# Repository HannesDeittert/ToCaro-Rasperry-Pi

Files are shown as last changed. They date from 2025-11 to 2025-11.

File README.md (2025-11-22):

# ToCaro-Raspberry-Pi

#### Funktionsweise

Das Seil wird über einen Getriebemotor auf eine Seilwinde aufgezogen (siehe CAD-Modell). Die Regelung des Motors erfolgt dabei positionsgesteuert über Hall-Encoder die am Motor verbaut sind. Beim Drehen des Motors werden Rechtecksignale an den digitalen Input des Arduinos gesendet. Die Software kann dann die ausgelösten Flanken erkennen und so durch Zählen der Schritte die Position bestimmen. Die Ansteuerung des Motors erfolgt aktuell über das adafruit motor shield v2.3 welches mittels I2C mit dem Arduino verbunden ist. Auf dem shield sitzen drei chips, ein PCA9685 der das I2C Signal des Arduinos in PWM Signale Wandelt und zwei TB6612 MOSFETs die daraus die Spannung an die Motoren freigaben. Den aktuellen Code hab ich dir auf der nextcloud abgelegt. 

#### Ziel

Grundsätzlich soll erstmal alles so funktionieren wie es jetzt funktioniert, nur statt mit dem Arduino mit einem Raspberry Pi 5 betrieben werden. 
In einem ersten Schritt wäre es klasse, wenn du die Motorsteuerung über das Adafruit Motor Shield statt mit dem Arduino mit dem Pi laufen lässt. Dabei reicht es auch wenn erstmal ein Motor läuft.
Alex hat ein PCB designed auf dem (neben anderen Sachen) Power Delivery und die chips des motor shields drauf sind. Am Ende soll alles darüber laufen. Bis das da ist, denke ich du kannst ganz gut vorarbeiten wenn du nur den Arduino durch den PI ersetzt. Auf dem finalen Board sollte dann ja eigentlich alles genauso laufen :D  

#### Links zu den Bauteilen

Motor https://www.dfrobot.com/product-1436.html
Adafruit Motor Shield V2.3 https://www.adafruit.com/product/1438
PWM Chip auf dem Motor Shield PCA9685 https://www.digikey.de/de/htmldatasheets/production/1640697/0/0/1/pca9685-datasheet
TB6612 MOSFET auf dem Motor Shield https://www.digikey.de/en/products/detail/toshiba-semiconductor-and-storage/TB6612FNG-C-8-EL/1730070

#### Raspberry Pi Code (neu)

Der Pi-Code liegt unter `raspberry_pi/` als Python-Paket `tocado_pi`:
- `src/tocado_pi/hardware.py` – Adapter für Motor Shield (PCA9685/TB6612) und Encoder.
- `src/tocado_pi/motor_control.py` – einfache Positionsregelung mit Grenzen/Sicherheits-Timeout.
- `src/tocado_pi/cli.py` – kleines CLI zum Drehen/Positionieren (`python -m tocado_pi.cli spin --duty 0.5 --seconds 2`).
- `scripts/smoke_test.py` – minimalistischer Spin-Test.
- `tests/` – pytest-Tests mit fakes (kein echtes Hardware-Setup nötig).

Setup auf dem Pi:
```
cd raspberry_pi
python -m venv .venv
source .venv/bin/activate
pip install -r requirements.txt -r dev-requirements.txt
pytest
PYTHONPATH=src python -m tocado_pi.cli --help
```

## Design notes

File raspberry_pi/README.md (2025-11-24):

# Raspberry Pi code guide

Raspberry Pi control code for the Adafruit Motor Shield V2.3 (PCA9685 + TB6612) with Hall encoders.

## Layout
- `src/tocado_pi/config.py` – config dataclasses (pins, I2C, motion limits).
- `src/tocado_pi/hardware.py` – hardware adapters (MotorKit driver + encoder GPIO reader).
- `src/tocado_pi/motor_control.py` – simple move/spin controls with limits and stop.
- `src/tocado_pi/cli.py` – CLI entrypoint (`spin`, `move`).
- `scripts/smoke_test.py` – minimal spin test helper.
- `scripts/debug_motor_shield.py` – interactive checker for supply, all 4 channels, and encoder ticks.
- `scripts/motor_web_ui.py` – small web UI to view encoder counts and jog one or several motor channels.
- `tests/` – pytest unit tests with fakes (no hardware needed).
- `requirements.txt` / `dev-requirements.txt` – runtime vs. dev deps.

## Quickstart (on the Pi)
```
cd raspberry_pi
python3 -m venv .venv
source .venv/bin/activate
pip install -r requirements.txt -r dev-requirements.txt
```

Check I2C for the Motor Shield (expect address 0x60):
```
i2cdetect -y 1
```

Run tests (offline):
```
pytest
```

CLI examples (set your encoder GPIO BCM pins):
```
PYTHONPATH=src python -m tocado_pi.cli spin --duty 0.3 --seconds 2 --pin-a <BCM_A> --pin-b <BCM_B> --motor-channel 1
PYTHONPATH=src python -m tocado_pi.cli move --target 500 --duty 0.5 --pin-a <BCM_A> --pin-b <BCM_B>
```

Smoke test script (short spin):
```
PYTHONPATH=src python scripts/smoke_test.py --duty 0.4 --seconds 2 --pin-a <BCM_A> --pin-b <BCM_B>
```

Debug the shield (pulses M1–M4, prompts for terminal observations, reports encoder counts):
```
PYTHONPATH=src python scripts/debug_motor_shield.py --duty 1.0 --seconds 1 --pin-a <BCM_A> --pin-b <BCM_B>
```

Web UI (encoder readout + forward/reverse/brake controls):
```
PYTHONPATH=src python scripts/motor_web_ui.py --motor-channel 1 --pin-a <BCM_A> --pin-b <BCM_B>
# Multi-motor example with three encoders:
# PYTHONPATH=src python scripts/motor_web_ui.py --motor 1:17:27 --motor 2:22:23 --motor 3:24:25
# Then open http://<pi-ip>:8000 in your browser.
```

## Wiring notes
- Motor Shield uses only I2C to the Pi; motors on M1–M4 terminals with separate motor supply.
- Encoders: treat A/B as open-collector; power at 3.3 V, GND common, use Pi pull-ups (`INPUT_PULLUP` default in code). Pi GPIOs are not 5 V tolerant; if you must use 5 V on the encoder side, add level shifting or pull-ups to 3.3 V instead.

## Files and intent
- `hardware.py`: isolates MotorKit import and GPIO usage; supports injecting fakes for tests.
- `motor_control.py`: moves toward a target encoder count with bounds, timeout, stop flag; spins for a duration.
- `cli.py`: convenient manual control without writing code; logs at INFO by default.
- `tests/test_motor_control.py`: covers move/timeout/spin behavior using fake motor + encoder.

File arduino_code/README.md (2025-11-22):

# Arduino sketches overview

Reference notes for the existing Arduino implementations that drive the Adafruit Motor Shield V2.3 (PCA9685 + dual TB6612). This summarizes wiring, data flow, and behavior to inform the Raspberry Pi port.

## Wiring / pinout
- Motor Shield V2.3 on I2C (addr 0x60 by default) using Arduino SDA/SCL.
- Motors: M1, M2, M3 outputs on the shield (no M4 in current code).
- Hall encoders (quadrature) per motor:  
  - Motor 1: `ENC1_A = 2`, `ENC1_B = 3`  
  - Motor 2: `ENC2_A = 8`, `ENC2_B = 9`  
  - Motor 3: `ENC3_A = 6`, `ENC3_B = 7`
- Interrupts are attached on the A channels only (`CHANGE` on ENC*_A). ISR reads A and B to determine direction.
- Pull-ups: all encoder inputs use `INPUT_PULLUP`.

## Sketch summaries
### Three_Motors_Chat.ino (main logic)
- Initializes three DC motors and three quadrature encoders.
- Persisted position per motor in EEPROM as signed long; guarded by magic value `0xBEEF`.
- Encoder ISR per motor:
  - Runs on A channel edges, reads A/B to increment or decrement a volatile count.
  - Updates `lastChange*` timestamps used to decide when to write EEPROM.
- Setup:
  - Loads encoder counts from EEPROM (or zeros and writes defaults).
  - Computes target steps from desired travel distances:  
    `stepsPerMM = hall_feedback_resolution / (2π * (winch_diameter/2))`  
    Targets: distance1=25mm, distance2=35mm, distance3=35mm.
  - Motors: speeds set to 30/40/40; initial direction FORWARD.
- Loop behavior:
  - Copies volatile counts atomically.
  - Direction control per motor: if count >= steps target, run BACKWARD; if count < 0, run FORWARD. This creates a back-and-forth motion between 0 and the target count.
  - Every `T_IDLE = 5000ms`, if a motor’s count changed since last save, writes all three counts to EEPROM.
  - Prints counts vs targets for all motors, then delays `delaytime = 100ms`.

### Wire_Tensioning.ino
- Minimal setup to spin only motor 2 at speed 20 (M1 and M3 are stopped).
- No encoder usage; likely a quick tensioning/smoke test.

### EEPROM_Clear.ino
- Utility to clear the entire EEPROM to `0xFF` via `EEPROM.update` loop; prints progress over Serial.

## Behavioral notes / assumptions
- Control loop is open-loop on PWM speed with closed-loop only on position count bounds (no PID). The motor reverses at 0 and at the computed step limit.
- Encoder resolution constant: `hall_feedback_resolution = 1050/2` (counts per revolution / 2?). Winch diameter = 7.0 units (likely mm).
- Persistence occurs only after 5s of inactivity per motor to reduce EEPROM wear.
- Serial output at 115200 baud: simple telemetry of counts/targets.

## Raspberry Pi porting considerations
- Replace Adafruit_MotorShield C++ library with `adafruit-circuitpython-motorkit` (PCA9685 + TB6612) over I2C.
- Use GPIO edge detection for encoder A channels; read B to determine direction. Apply debouncing if needed.
- Provide configurable pin mapping, winch diameter, encoder resolution, speed/limit values.
- Add safety: max runtime/travel, faulted motor disable, optional soft-start on speed changes.
- Mirror EEPROM persistence via a JSON/state file (or skip) to preserve position across reboots if required.

These notes should keep Arduino intent visible while we build the Raspberry Pi implementation.

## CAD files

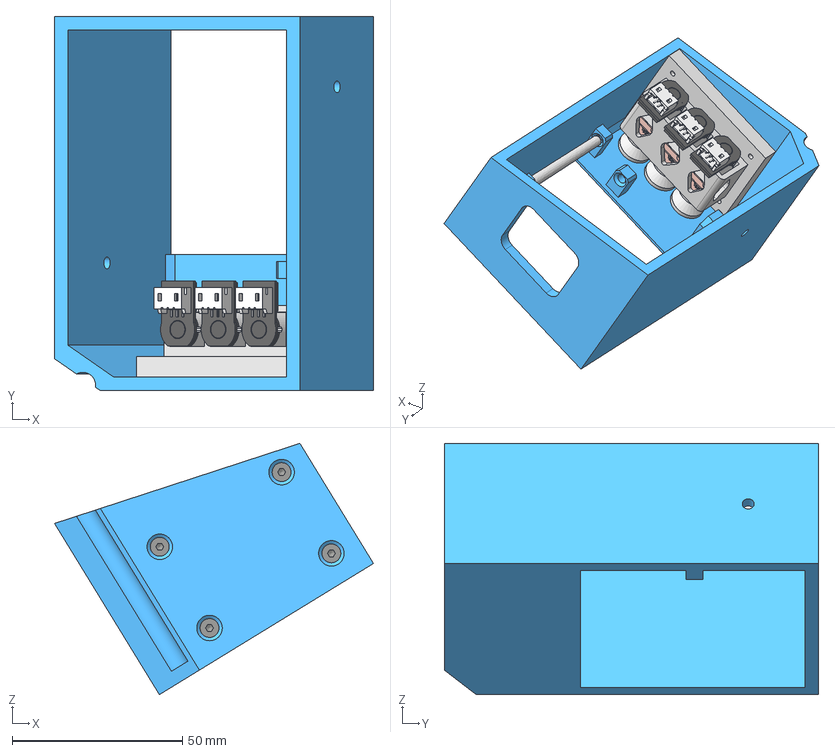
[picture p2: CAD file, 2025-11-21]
cad_doc/ElectronicsV2.stp
93.7 x 110.0 x 73.9 mm
Motorhalter Electronics Box V4
ruthex RX-M3-5,7 x 4
Gearmotor, Micro Metal, 50.1, with Driver_1 x 3
C-1775469-3 x 3
PCBA x 3
Seilwinde x 3
ISO 10642 - M3 x 8 x 7
Electronics Box V5
Tube1

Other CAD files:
cad_doc/ElectronicsV2.iam

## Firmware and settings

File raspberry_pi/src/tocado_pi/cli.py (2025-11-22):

"""
Small CLI for manual Raspberry Pi motor checks.

Examples:
- Spin for 2 seconds at 50% duty: `python -m tocado_pi.cli spin --duty 0.5 --seconds 2`
- Move to encoder count 500 at 60% duty: `python -m tocado_pi.cli move --target 500 --duty 0.6`
"""

from __future__ import annotations

import argparse
import logging
import sys

from .config import EncoderConfig, MotorConfig, MotionLimits, MotorShieldConfig
from .hardware import EncoderReader, build_motorkit_driver
from .motor_control import MotorController


def _build_config_from_args(args: argparse.Namespace) -> MotorConfig:
    return MotorConfig(
        shield=MotorShieldConfig(
            motor_channel=args.motor_channel,
            i2c_address=args.i2c_address,
            i2c_busnum=args.i2c_bus,
            default_duty=args.default_duty,
        ),
        encoder=EncoderConfig(pin_a=args.pin_a, pin_b=args.pin_b, pull_up=not args.no_pullup),
        limits=MotionLimits(
            min_count=args.min_count,
            max_count=args.max_count,
            max_runtime_s=args.max_runtime,
            poll_interval_s=args.poll_interval,
            stop_tolerance=args.tolerance,
        ),
        name=args.name,
    )


def _add_shared_args(parser: argparse.ArgumentParser) -> None:
    # Defaults are conservative; override for your wiring. Pins are BCM numbers.
    parser.add_argument("--pin-a", type=int, default=17, help="BCM pin for encoder A")
    parser.add_argument("--pin-b", type=int, default=27, help="BCM pin for encoder B")
    parser.add_argument("--no-pullup", action="store_true", help="Disable pull-ups on encoder pins")
    parser.add_argument("--motor-channel", type=int, default=1, help="Motor channel on shield (1-4)")
    parser.add_argument("--i2c-address", type=lambda x: int(x, 0), default=0x60, help="I2C address of Motor Shield")
    parser.add_argument("--i2c-bus", type=int, default=1, help="I2C bus number to use")
    parser.add_argument("--default-duty", type=float, default=0.5, help="Default duty (0..1)")
    parser.add_argument("--min-count", type=int, default=0, help="Lower encoder bound")
    parser.add_argument("--max-count", type=int, default=10_000, help="Upper encoder bound")
    parser.add_argument("--tolerance", type=int, default=0, help="Stop tolerance in counts")
    parser.add_argument("--max-runtime", type=float, default=15.0, help="Max runtime seconds before timeout")
    parser.add_argument("--poll-interval", type=float, default=0.01, help="Polling interval seconds")
    parser.add_argument("--name", type=str, default="motor1", help="Logical motor name for logs")
    parser.add_argument("--log-level", default="INFO", choices=["DEBUG", "INFO", "WARNING", "ERROR"])


def build_parser() -> argparse.ArgumentParser:
    parser = argparse.ArgumentParser(description="Adafruit Motor Shield test CLI")
    sub = parser.add_subparsers(dest="command", required=True)

    common = argparse.ArgumentParser(add_help=False)
    _add_shared_args(common)

    spin = sub.add_parser("spin", parents=[common], help="Spin at duty for a duration")
    spin.add_argument("--duty", type=float, required=True, help="Duty cycle -1..1 (sign sets direction)")
    spin.add_argument("--seconds", type=float, default=2.0, help="Duration to spin")

    move = sub.add_parser("move", parents=[common], help="Move to a target encoder count")
    move.add_argument("--target", type=int, required=True, help="Target encoder count")
    move.add_argument("--duty", type=float, default=None, help="Duty 0..1 (direction inferred)")
    move.add_argument("--timeout", type=float, default=None, help="Optional timeout override")

    return parser


def main(argv: list[str] | None = None) -> int:
    parser = build_parser()
    args = parser.parse_args(argv)
    logging.basicConfig(level=getattr(logging, args.log_level))

    cfg = _build_config_from_args(args)

    encoder = EncoderReader(cfg.encoder, name=f"{cfg.name}-encoder")
    encoder.start()
    motor = build_motorkit_driver(cfg.shield)
    controller = MotorController(motor, encoder, cfg)

    try:
        if args.command == "spin":
            result = controller.spin_for(args.duty, args.seconds)
        elif args.command == "move":
            result = controller.move_to_count(args.target, duty=args.duty, timeout_s=args.timeout)
        else:  # pragma: no cover - argparse enforces commands
            parser.error("unknown command")
            return 2
    finally:
        encoder.stop()
        motor.brake()

    status = "ok" if result.reached else "not-reached"
    print(f"{cfg.name} finished: {status}, final={result.final_count}, target={result.target}, elapsed={result.elapsed_s:.2f}s")
    return 0


if __name__ == "__main__":  # pragma: no cover
    raise SystemExit(main())

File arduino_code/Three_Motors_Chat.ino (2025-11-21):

#include <Wire.h>
#include <Adafruit_MotorShield.h>
#include <EEPROM.h>
#include <Arduino.h>

// Encoder-Pins
const uint8_t ENC1_A=2, ENC1_B=3, ENC2_A=8, ENC2_B=9, ENC3_A=6, ENC3_B=7;

// Motor Shield V2
Adafruit_MotorShield AFMS = Adafruit_MotorShield();
Adafruit_DCMotor *m1, *m2, *m3;

// Encoder-Zähler
volatile long cnt1=0, cnt2=0, cnt3=0;

// Ziele/Parameter
float distance1=25, distance2=35, distance3=35;
int motorspeed1 = 30, motorspeed2 =40, motorspeed3 = 40;
float winch_diameter=7.0;
float hall_feedback_resolution=1050.0/2.0;
int steps1=0, steps2=0, steps3=0;
int delaytime = 100;

// EEPROM
struct Persist { long p1,p2,p3; uint16_t magic; };
const uint16_t MAGIC=0xBEEF;
bool loadEEPROM(long &o1,long &o2,long &o3){
  Persist p; EEPROM.get(0,p);
  if(p.magic==MAGIC){ o1=p.p1; o2=p.p2; o3=p.p3; return true; }
  return false;
}
void saveEEPROM(long o1,long o2,long o3){
  Persist p{ o1,o2,o3,MAGIC }; EEPROM.put(0,p);
}

// Zeitstempel je Motor
unsigned long lastChange1=0,lastChange2=0,lastChange3=0;
long lastSaved1=0,lastSaved2=0,lastSaved3=0;

// ISRs – jede liest nur ihren Encoder
void isrEnc1(){ bool a=digitalRead(ENC1_A), b=digitalRead(ENC1_B); (a==b)?cnt1++:cnt1--; lastChange1=millis(); }
void isrEnc2(){ bool a=digitalRead(ENC2_A), b=digitalRead(ENC2_B); (a==b)?cnt2++:cnt2--; lastChange2=millis(); }
void isrEnc3(){ bool a=digitalRead(ENC3_A), b=digitalRead(ENC3_B); (a==b)?cnt3++:cnt3--; lastChange3=millis(); }

void setup(){
  Serial.begin(115200);
  pinMode(ENC1_A,INPUT_PULLUP); pinMode(ENC1_B,INPUT_PULLUP);
  pinMode(ENC2_A,INPUT_PULLUP); pinMode(ENC2_B,INPUT_PULLUP);
  pinMode(ENC3_A,INPUT_PULLUP); pinMode(ENC3_B,INPUT_PULLUP);

  long o1=0,o2=0,o3=0;
  if(!loadEEPROM(o1,o2,o3)){ o1=o2=o3=0; saveEEPROM(o1,o2,o3); }
  noInterrupts(); cnt1=o1; cnt2=o2; cnt3=o3; interrupts();
  lastSaved1=cnt1; lastSaved2=cnt2; lastSaved3=cnt3;

  float stepsPerMM = hall_feedback_resolution / (2.0*PI*(winch_diameter/2.0));
  steps1 = int(distance1*stepsPerMM);
  steps2 = int(distance2*stepsPerMM);
  steps3 = int(distance3*stepsPerMM);

  // UNO R4: attachInterrupt auf A-Kanäle
  attachInterrupt(digitalPinToInterrupt(ENC1_A), isrEnc1, CHANGE);
  attachInterrupt(digitalPinToInterrupt(ENC2_A), isrEnc2, CHANGE);
  attachInterrupt(digitalPinToInterrupt(ENC3_A), isrEnc3, CHANGE);

  AFMS.begin(); // Motor Shield initialisieren
  m1=AFMS.getMotor(1); m2=AFMS.getMotor(2); m3=AFMS.getMotor(3);
  m1->setSpeed(motorspeed1); m1->run(FORWARD);
  m2->setSpeed(motorspeed2); m2->run(FORWARD);
  m3->setSpeed(motorspeed3); m3->run(FORWARD);
}

void loop(){
  noInterrupts(); long c1=cnt1,c2=cnt2,c3=cnt3; interrupts();

  if(c1>=steps1) m1->run(BACKWARD); else if(c1<0) m1->run(FORWARD);
  if(c2>=steps2) m2->run(BACKWARD); else if(c2<0) m2->run(FORWARD);
  if(c3>=steps3) m3->run(BACKWARD); else if(c3<0) m3->run(FORWARD);

  const unsigned long T_IDLE=5000;
  if(millis()-lastChange1>T_IDLE && c1!=lastSaved1){ lastSaved1=c1; saveEEPROM(lastSaved1,lastSaved2,lastSaved3); }
  if(millis()-lastChange2>T_IDLE && c2!=lastSaved2){ lastSaved2=c2; saveEEPROM(lastSaved1,lastSaved2,lastSaved3); }
  if(millis()-lastChange3>T_IDLE && c3!=lastSaved3){ lastSaved3=c3; saveEEPROM(lastSaved1,lastSaved2,lastSaved3); }

  Serial.print("M1 "); Serial.print(c1); Serial.print('/'); Serial.print(steps1);
  Serial.print("  M2 "); Serial.print(c2); Serial.print('/'); Serial.print(steps2);
  Serial.print("  M3 "); Serial.print(c3); Serial.print('/'); Serial.println(steps3);


  delay(delaytime);
}

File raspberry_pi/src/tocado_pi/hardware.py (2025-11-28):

"""
Hardware adapters for the Adafruit Motor Shield V2.3 and quadrature encoders.

The goal is to keep hardware-specific code isolated so the controller can be
unit-tested with fakes. Imports of `adafruit_motorkit` and `RPi.GPIO` are kept
lazy to avoid failures on non-Pi development machines.
"""

from __future__ import annotations

import logging
import threading
from dataclasses import dataclass
from typing import Optional

from .config import EncoderConfig, MotorShieldConfig

LOG = logging.getLogger(__name__)


def _clamp(value: float, low: float = -1.0, high: float = 1.0) -> float:
    return max(low, min(high, value))


class MotorDriver:
    """
    Thin wrapper around an Adafruit DC motor to normalize throttle/brake calls.
    Keeps the rest of the code independent from the underlying library.
    """

    def __init__(self, motor, name: str = "motor"):
        self._motor = motor
        self.name = name

    def set_throttle(self, duty: float) -> None:
        """
        Set normalized duty cycle: -1..1 where sign controls direction.
        """
        duty = _clamp(duty)
        LOG.debug("%s throttle -> %.3f", self.name, duty)
        self._motor.throttle = duty

    def brake(self) -> None:
        """Active brake the motor."""
        LOG.debug("%s brake", self.name)
        self._motor.throttle = 0.0

    def release(self) -> None:
        """Release (coast) the motor."""
        LOG.debug("%s release", self.name)
        self._motor.throttle = None


def build_motorkit_driver(cfg: MotorShieldConfig, *, i2c=None) -> MotorDriver:
    """
    Instantiate a MotorDriver using adafruit-circuitpython-motorkit.

    The optional `i2c` parameter allows passing a pre-created I2C bus.
    """
    try:
        from adafruit_motorkit import MotorKit
    except ImportError as exc:  # pragma: no cover - exercised on hardware
        raise RuntimeError(
            "adafruit-circuitpython-motorkit is not available; "
            "install requirements and run on a Raspberry Pi."
        ) from exc

    kit = MotorKit(address=cfg.i2c_address, i2c=i2c)
    motor_map = {
        1: kit.motor1,
        2: kit.motor2,
        3: kit.motor3,
        4: kit.motor4,
    }
    motor = motor_map.get(cfg.motor_channel)
    if motor is None:
        raise ValueError(f"motor_channel must be 1-4, got {cfg.motor_channel}")
    return MotorDriver(motor, name=f"motor{cfg.motor_channel}")


class EncoderReader:
    """
    Quadrature encoder reader driven by GPIO edge interrupts on channel A.

    Expected wiring:
    - Encoder powered at 3.3 V (recommended to keep GPIO safe), common GND.
    - A/B connected to BCM pins configured with pull-ups (default).
    - If encoder must be at 5 V: use level shifting or pull-ups to 3.3 V.
    """

    def __init__(
        self,
        cfg: EncoderConfig,
        *,
        gpio=None,
        name: str = "encoder",
    ) -> None:
        self.cfg = cfg
        self.name = name
        self._gpio = gpio  # allows injecting fake GPIO in tests
        self._count = 0
        self._lock = threading.Lock()
        self._started = False

    def _ensure_gpio(self):
        if self._gpio:
            return self._gpio
        try:
            import RPi.GPIO as GPIO  # type: ignore
        except ImportError as exc:  # pragma: no cover - exercised on hardware
            raise RuntimeError(
                "RPi.GPIO not available; run on Raspberry Pi or inject a GPIO stub."
            ) from exc
        self._gpio = GPIO
        return GPIO

    def start(self) -> None:
        """
        Configure GPIO pins and register an interrupt on channel A.
        Call once before reading; safe to call multiple times.
        """
        if self._started:
            return
        GPIO = self._ensure_gpio()
        GPIO.setmode(GPIO.BCM)
        pull = GPIO.PUD_UP if self.cfg.pull_up else GPIO.PUD_OFF
        GPIO.setup(self.cfg.pin_a, GPIO.IN, pull_up_down=pull)
        GPIO.setup(self.cfg.pin_b, GPIO.IN, pull_up_down=pull)
        kwargs = {}
        if self.cfg.debounce_ms and self.cfg.debounce_ms > 0:
            kwargs["bouncetime"] = self.cfg.debounce_ms
        GPIO.add_event_detect(
            self.cfg.pin_a,
            GPIO.BOTH,
            callback=self._handle_edge,
            **kwargs,
        )
        self._started = True
        LOG.info("%s listening on A=%s B=%s", self.name, self.cfg.pin_a, self.cfg.pin_b)

    def stop(self) -> None:
        if not self._started:
            return
        GPIO = self._ensure_gpio()
        if GPIO.getmode() is not None:
            GPIO.remove_event_detect(self.cfg.pin_a)
        self._started = False

    def _handle_edge(self, channel) -> None:
        GPIO = self._ensure_gpio()
        a_state = GPIO.input(self.cfg.pin_a)
        b_state = GPIO.input(self.cfg.pin_b)
        delta = 1 if a_state == b_state else -1
        with self._lock:
            self._count += delta

    def read(self) -> int:
        """
        Return the latest signed count.
        """
        with self._lock:
            return int(self._count)

    def reset(self, value: int = 0) -> None:
        with self._lock:
            self._count = value

    # Convenience for offline tests without GPIO callbacks
    def simulate_ticks(self, delta: int) -> None:
        with self._lock:
            self._count += delta

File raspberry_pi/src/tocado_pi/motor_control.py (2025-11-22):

"""
High-level motor control primitives built on top of MotorDriver + EncoderReader.
"""

from __future__ import annotations

import logging
import time
from dataclasses import dataclass
from typing import Callable, Optional

from .config import MotorConfig
from .hardware import MotorDriver, EncoderReader

LOG = logging.getLogger(__name__)


def _clamp(value: float, low: float = -1.0, high: float = 1.0) -> float:
    return max(low, min(high, value))


@dataclass
class MoveResult:
    target: int
    final_count: int
    elapsed_s: float
    reached: bool


class MotorController:
    """
    Minimal position and motion helpers for a single DC motor.

    Design notes:
    - Uses simple open-loop duty + encoder feedback for stop conditions.
    - Enforces bounds (min/max count) and a runtime timeout.
    - Can be exercised with fakes by injecting motor, encoder, now/sleep.
    """

    def __init__(
        self,
        motor: MotorDriver,
        encoder: EncoderReader,
        cfg: MotorConfig,
        *,
        now: Callable[[], float] = time.monotonic,
        sleep: Callable[[float], None] = time.sleep,
    ) -> None:
        self.motor = motor
        self.encoder = encoder
        self.cfg = cfg
        self._now = now
        self._sleep = sleep
        self._stop_flag = False

    def emergency_stop(self) -> None:
        self._stop_flag = True
        self.motor.brake()
        LOG.warning("%s emergency stop triggered", self.cfg.name)

    def spin_for(self, duty: float, seconds: float) -> MoveResult:
        """
        Spin at a fixed duty cycle for a duration (no position target).
        """
        duty = _clamp(duty)
        start = self._now()
        deadline = start + min(seconds, self.cfg.limits.max_runtime_s)
        LOG.info("%s spin_for duty=%.2f duration=%.2fs", self.cfg.name, duty, seconds)
        self.motor.set_throttle(duty)
        while self._now() < deadline and not self._stop_flag:
            self._sleep(self.cfg.limits.poll_interval_s)
        self.motor.brake()
        end_count = self.encoder.read()
        elapsed = self._now() - start
        return MoveResult(target=end_count, final_count=end_count, elapsed_s=elapsed, reached=not self._stop_flag)

    def move_to_count(
        self,
        target_count: int,
        *,
        duty: Optional[float] = None,
        timeout_s: Optional[float] = None,
    ) -> MoveResult:
        """
        Move until the encoder count reaches target_count within tolerance.

        Stops on:
        - reaching target within tolerance
        - timeout
        - bounds violation
        - emergency_stop flag
        """
        limits = self.cfg.limits
        if target_count < limits.min_count or target_count > limits.max_count:
            raise ValueError(f"target_count {target_count} is outside [{limits.min_count}, {limits.max_count}]")

        duty = abs(duty if duty is not None else self.cfg.shield.default_duty)
        duty = _clamp(duty, 0.0, 1.0)

        start_count = self.encoder.read()
        direction = 1 if target_count >= start_count else -1
        timeout = timeout_s if timeout_s is not None else limits.max_runtime_s
        start_time = self._now()
        deadline = start_time + timeout

        LOG.info(
            "%s move_to target=%s from=%s duty=%.2f dir=%+d timeout=%.1fs",
            self.cfg.name,
            target_count,
            start_count,
            duty,
            direction,
            timeout,
        )

        self.motor.set_throttle(direction * duty)
        reached = False
        while not self._stop_flag:
            current = self.encoder.read()
            if _within_tolerance(current, target_count, limits.stop_tolerance):
                reached = True
                break
            if self._now() > deadline:
                LOG.warning("%s move_to timeout current=%s target=%s", self.cfg.name, current, target_count)
                break
            if current < limits.min_count or current > limits.max_count:
                LOG.error(
                    "%s count %s exceeded limits [%s,%s]; braking",
                    self.cfg.name,
                    current,
                    limits.min_count,
                    limits.max_count,
                )
                break
            self._sleep(limits.poll_interval_s)

        self.motor.brake()
        elapsed = self._now() - start_time
        final_count = self.encoder.read()
        if not reached and self._stop_flag:
            LOG.warning("%s move_to interrupted by stop", self.cfg.name)
        return MoveResult(target=target_count, final_count=final_count, elapsed_s=elapsed, reached=reached)


def _within_tolerance(value: int, target: int, tol: int) -> bool:
    if tol <= 0:
        return value == target
    return target - tol <= value <= target + tol

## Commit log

2025-11-21 Folder structure
    [ElectronicsV2.iam, ElectronicsV2.stp]
2025-11-22 RaspberryPi code
2025-11-27 Motor 1- Debugg
2025-11-28 Using Encoder
2025-11-28 Add motor calibration UI with slider and faster refresh
2025-11-28 motor keyboard
